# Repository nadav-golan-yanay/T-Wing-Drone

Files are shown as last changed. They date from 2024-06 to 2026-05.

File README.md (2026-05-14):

# T-Wing-Drone

**T-Wing** is a custom VTOL drone project I built as my final-year project in the Robotics program at Gvanim High School.  
The platform uses **three motors**, each mounted on a **servo-driven rotating mechanism**, combining multirotor control with custom mechanical design.

## Repository contents

This repository currently includes:

- `V22 full assembly 3D files/` — STL files for the full mechanical assembly
- `T-Wing_Params.params` — flight-controller parameter set
- `arducopter.apj` — ArduPilot firmware package used in this project

## Project highlights

- Custom airframe and wing/motor mounting system
- 3D-printed structural parts (PLA + ABS) with carbon-fiber reinforcements
- Iterative design based on real flight-test feedback
- Migration from early ESP32/Arduino prototypes to Pixhawk-based control

## Proof of success / flight tests

It took almost a year from the initial concept to the first successful takeoff.  
Flight tests are documented on my YouTube channel **NJGeek**:

- Channel: <https://www.youtube.com/channel/UCFTb9_tvUnTDQ8KEI29btOw>
- Playlist: <https://youtube.com/playlist?list=PLqjej9Hx4NUbdtqtBohuQlDSfjigC6vUl&si=ENThvdS27YvLaflj>

### First successful flight

My first successful flight was on **2023-05-19**:

- Video: <https://youtu.be/v9YFX8xqOcs>
- Clip asset:  
  <https://github.com/nadav-golan-yanay/T-Wing-Drone/assets/78790309/edb56a76-8f06-4417-a14c-41ca4fd376b4>

## Parts and 3D models

All model files are available in:

- [`V22 full assembly 3D files`](./V22%20full%20assembly%203D%20files)

Modeling and manufacturing workflow:

- CAD: [Onshape](https://www.onshape.com/en/)
- 3D printing: [FlashForge](https://flashforge.com/)

TWing-Full-V22

The assembly is built from four main modules: a body and three wings.  
Main material is PLA, with ABS used for heat-sensitive parts and carbon-fiber rods for reinforcement.

### Motor holder design notes

Exploded_Motor_Holder

The motor holder connects to a carbon-fiber bar using a clamp-based solution.  
During testing, motor heat caused PLA deformation, so the design evolved through several iterations:

1. ABS-only holder (rejected due to poor layer adhesion under load)
2. ABS spacers between motor and PLA base (improved, but not enough over time)
3. Additional thermal isolation layer between base and spacers (successful in long runs)

## Boards and controllers

The final version of the drone used a **Pixhawk 4 Mini** flight controller.

| Parameter | ESP32 | Arduino Uno | Pixhawk 4 Mini |
| :--- | :---: | :---: | :---: |
| Memory | 520 KB | 32 KB | 2 MB |
| Code stack | C++ | C++ | ArduPilot |
| Weight | 10 g | 25 g | 37.2 g |
| I/O voltage | 3.3 V | 5 V | 5 V |

### Why ESP32 and Arduino were used in early stages

The project started with ESP32 and Arduino due to budget limitations and available school hardware.  
That phase enabled rapid prototyping of:

- a custom radio system: <https://github.com/nadav-golan-yanay/com.git>
- motor/servo extension logic: <https://github.com/nadav-golan-yanay/Extender.git>
- custom PID experiments: <https://github.com/nadav-golan-yanay/PID.git>

This early work helped build system-level understanding before moving to Pixhawk + ArduPilot.

## Code and parameters

This repository includes the configuration artifacts used in the project:

- Parameters file: [`T-Wing_Params.params`](./T-Wing_Params.params)
- Firmware package: [`arducopter.apj`](./arducopter.apj)

> **Safety note:** Flight parameters and firmware should be reviewed and adapted for your frame, propulsion system, and local safety rules before use.

## Original Hebrew project book

This project was originally documented as a full project book in Hebrew for the school robotics program.  
It includes the design process, engineering decisions, manufacturing notes, and flight-test development timeline behind T-Wing.
You can read it here:

https://docs.google.com/document/d/e/2PACX-1vRpgUPn3u3C4NKBrrm5369ePE8NgqHe6AcITnAAplzpBRE5xgx34mOA12HqonQQBGQqTkdLsOp1IHl_/pub

## Acknowledgments

I’m deeply grateful to everyone who helped make this project possible:

In this project, I received help from many people, whom I would like to thank. First and foremost, I would like to thank my subject teachers, [Gal Arbel](https://github.com/galarb) and [Oded Valensi](). Whether in modeling, programming, manufacturing, or writing the report, Gal and Oded were always by my side and supported me. Thank you for helping to push me to the limits of my abilities and beyond; under your guidance, even the sky is not the limit.

I want to extend my gratitude to my parents who supported me throughout the entire project and encouraged me to pursue this field. Thank you for every model airplane and drone you bought me, each one helped me gain the knowledge that enabled me to build this project. Many thanks to [Efi Kastiel](https://www.linkedin.com/search/results/all/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) from [Efix-Aviation](https://www.linkedin.com/company/efixaviation/?originalSubdomain=il), who donated equipment and provided training regarding the drone. A big thank you to [Ariel Dubrovinski](), who guided me on how to use the Pixhawk controller and how to work with PID systems.

Thank you to the students from grades 9 and 7: [Tomer Ozer](https://github.com/TomerOzer), [Noam Ron](https://github.com/NoamRon1), [Yehav Kosi Friedman](https://github.com/yahavkosoi), [Dan Katzenellenbogen](https://github.com/Dan-Katzenellenbogen), [Yoav Aharoni](), [Neta Shen-Or](), [Hadas Rahman](), and [Yoav Paz](https://github.com/YoavPaz). Thank you for your help in building the project and supporting the code, whether it was just holding a part while I drilled or reviewing the code. You all helped greatly, and for that, I thank you.

A special thank you to [Roee Glotman](https://github.com/Roee-dev), my classmate, who was my partner at the beginning of the project. Many thanks to my fellow students in the subject: [Yotam Sharon](), [Daniel Shor](), [Dror Chen](), [Ori Zalgman](), [Daniel Semelik](https://github.com/DanielSmelik), [Yuval Rahman](), [Eran Salomon]() and [Raviv Klein](https://github.com/raviviviviv). Thank you very much for the help and support, for being with me during flight tests, for helping me film, and for letting me print before you so I could progress. Thank you very much to the school for the lab and project funding.

Finally, a huge thank you to my (ex)girlfriend, Daria Hebron. Thank you for your support and understanding. Thank you for every glass of water or toast you brought me in the late hours of the night when I was sitting at the computer working, thank you for letting me use your car to transport equipment, and thank you for all the emotional support you provided during all the difficulties.

Thank you all for helping turn this idea into a flying system.

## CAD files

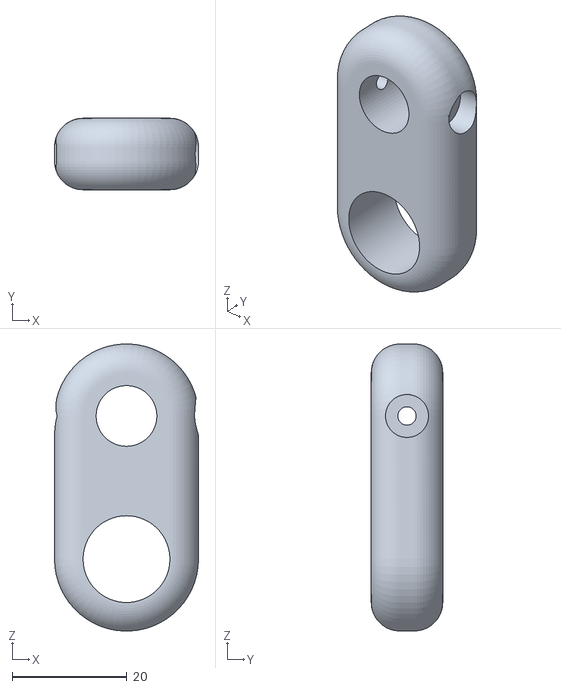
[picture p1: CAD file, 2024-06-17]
V22 full assembly 3D files/Biring Holder.stl
25.1 x 12.5 x 50.1

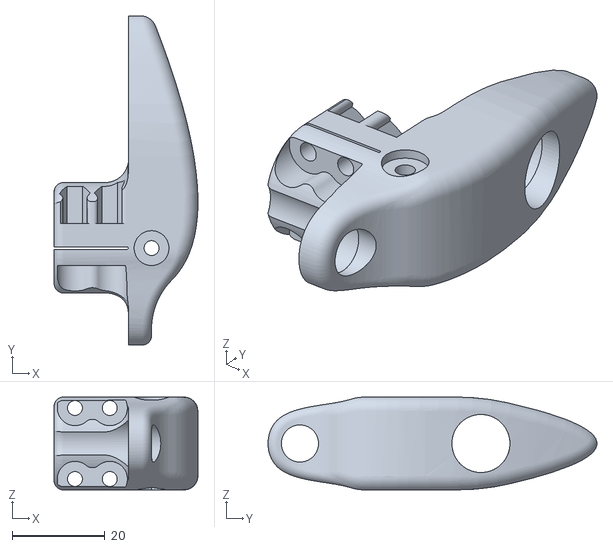
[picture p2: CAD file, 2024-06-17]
V22 full assembly 3D files/Carbon Fiber bar end.stl
31.0 x 70.9 x 20.0

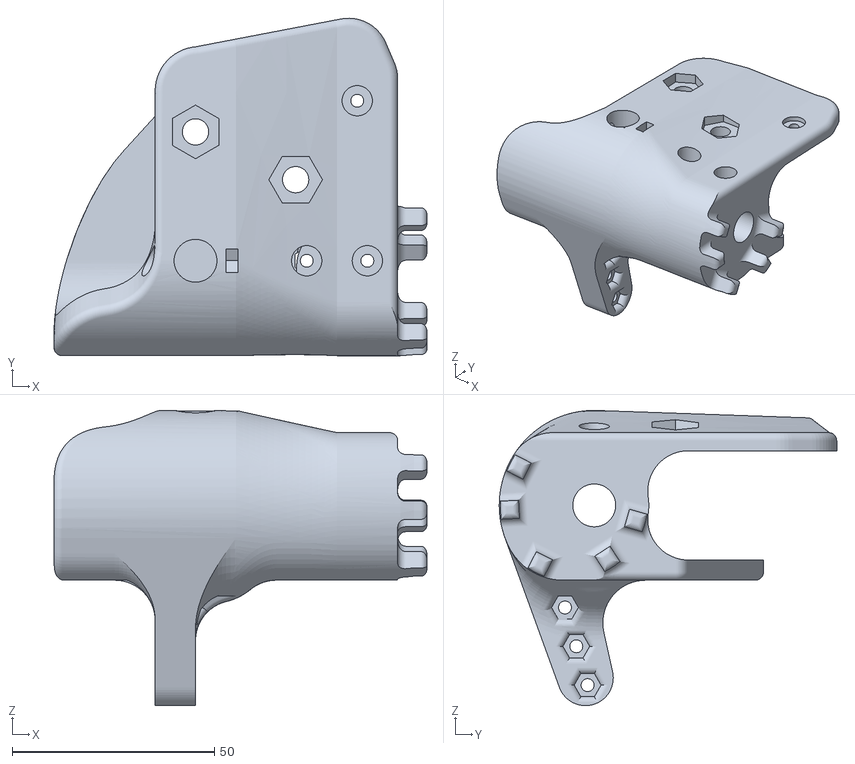
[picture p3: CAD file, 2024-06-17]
V22 full assembly 3D files/Wings Holder Left.stl
92.2 x 83.5 x 73.0

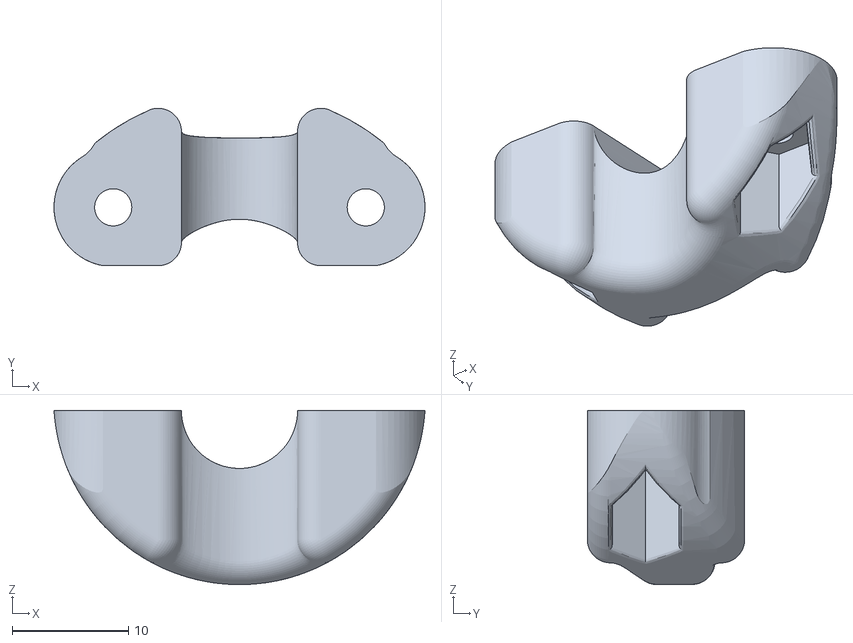
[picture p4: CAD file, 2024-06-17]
V22 full assembly 3D files/Motor holder to carbon fiber bar connector.stl
32.0 x 13.6 x 15.0

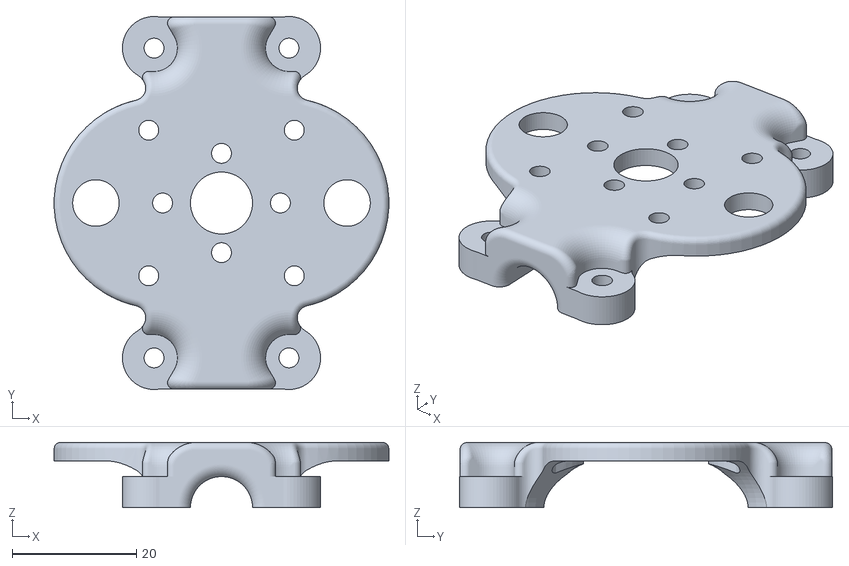
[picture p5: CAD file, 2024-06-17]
V22 full assembly 3D files/Motor Holder Base.stl
54.0 x 60.1 x 10.5

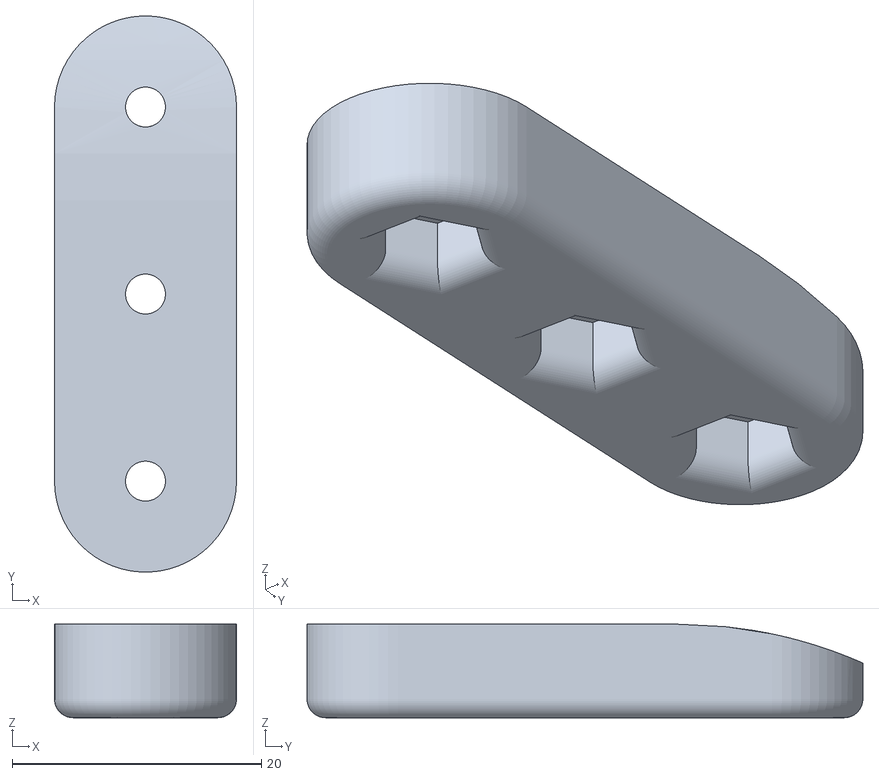
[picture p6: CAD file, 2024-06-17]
V22 full assembly 3D files/body to back wing connector.stl
14.6 x 44.6 x 7.50

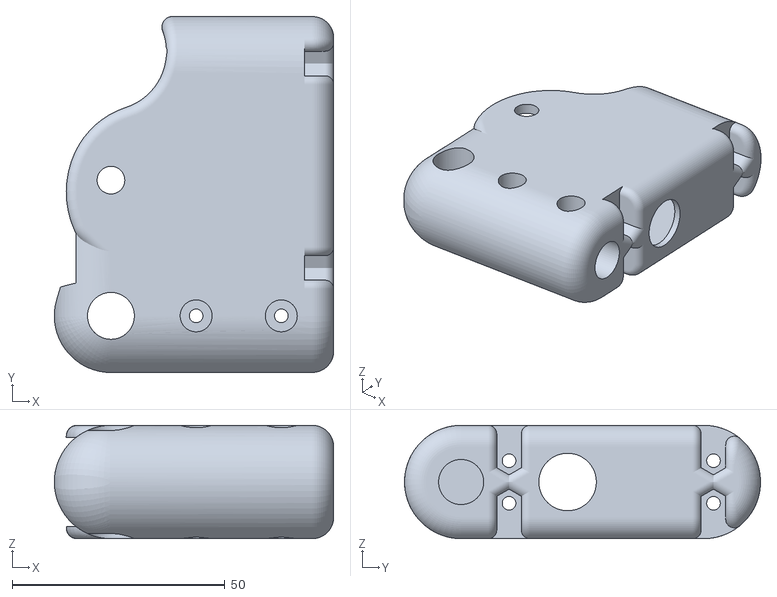
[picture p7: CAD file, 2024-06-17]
V22 full assembly 3D files/ Servo Holder.stl
65.6 x 83.6 x 26.6

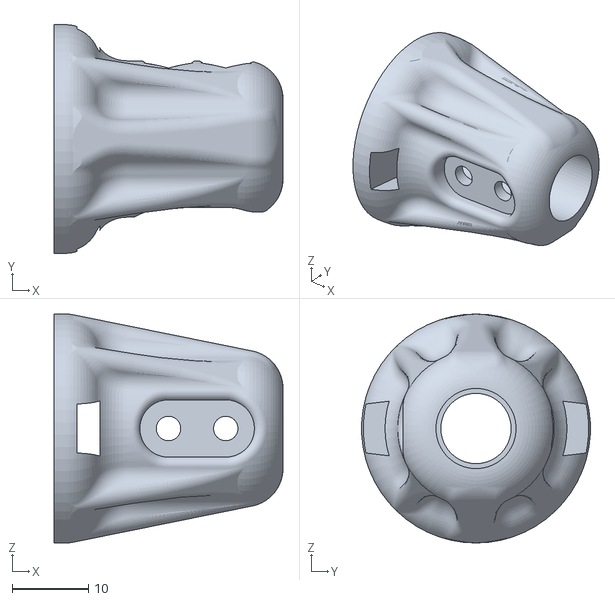
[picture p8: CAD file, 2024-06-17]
V22 full assembly 3D files/Stormtrooper helmet.stl
30.0 x 30.0 x 30.0

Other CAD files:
V22 full assembly 3D files/Body.stl
V22 full assembly 3D files/Wings Holder Right.stl

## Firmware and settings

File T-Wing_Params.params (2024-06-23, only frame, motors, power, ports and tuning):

1	1	ATC_ANGLE_BOOST	1	2
1	1	ATC_ANG_LIM_TC	1.000000000000000000	9
1	1	ATC_ANG_PIT_P	4.500000000000000000	9
1	1	ATC_ANG_RLL_P	4.500000000000000000	9
1	1	ATC_ANG_YAW_P	4.500000000000000000	9
1	1	ATC_RATE_FF_ENAB	1	2
1	1	ATC_RATE_P_MAX	0.000000000000000000	9
1	1	ATC_RATE_R_MAX	0.000000000000000000	9
1	1	ATC_RATE_Y_MAX	0.000000000000000000	9
1	1	ATC_RAT_PIT_D	0.003599999938160181	9
1	1	ATC_RAT_PIT_FF	0.000000000000000000	9
1	1	ATC_RAT_PIT_FLTD	20.000000000000000000	9
1	1	ATC_RAT_PIT_FLTE	0.000000000000000000	9
1	1	ATC_RAT_PIT_FLTT	20.000000000000000000	9
1	1	ATC_RAT_PIT_I	0.135000005364418030	9
1	1	ATC_RAT_PIT_IMAX	0.500000000000000000	9
1	1	ATC_RAT_PIT_P	0.135000005364418030	9
1	1	ATC_RAT_PIT_SMAX	0.000000000000000000	9
1	1	ATC_RAT_RLL_D	0.003599999938160181	9
1	1	ATC_RAT_RLL_FF	0.000000000000000000	9
1	1	ATC_RAT_RLL_FLTD	20.000000000000000000	9
1	1	ATC_RAT_RLL_FLTE	0.000000000000000000	9
1	1	ATC_RAT_RLL_FLTT	20.000000000000000000	9
1	1	ATC_RAT_RLL_I	0.135000005364418030	9
1	1	ATC_RAT_RLL_IMAX	0.500000000000000000	9
1	1	ATC_RAT_RLL_P	0.135000005364418030	9
1	1	ATC_RAT_RLL_SMAX	0.000000000000000000	9
1	1	ATC_RAT_YAW_D	0.000000000000000000	9
1	1	ATC_RAT_YAW_FF	0.000000000000000000	9
1	1	ATC_RAT_YAW_FLTD	100.000000000000000000	9
1	1	ATC_RAT_YAW_FLTE	2.500000000000000000	9
1	1	ATC_RAT_YAW_FLTT	20.000000000000000000	9
1	1	ATC_RAT_YAW_I	0.017999999225139618	9
1	1	ATC_RAT_YAW_IMAX	0.500000000000000000	9
1	1	ATC_RAT_YAW_P	0.180000007152557373	9
1	1	ATC_RAT_YAW_SMAX	0.000000000000000000	9
1	1	BATT2_MONITOR	0	2
1	1	BATT3_MONITOR	0	2
1	1	BATT4_MONITOR	0	2
1	1	BATT5_MONITOR	0	2
1	1	BATT6_MONITOR	0	2
1	1	BATT7_MONITOR	0	2
1	1	BATT8_MONITOR	0	2
1	1	BATT9_MONITOR	0	2
1	1	BATT_AMP_OFFSET	0.000000000000000000	9
1	1	BATT_AMP_PERVLT	36.363998413085937500	9
1	1	BATT_ARM_MAH	0	6
1	1	BATT_ARM_VOLT	0.000000000000000000	9
1	1	BATT_CAPACITY	1300	6
1	1	BATT_CRT_MAH	0.000000000000000000	9
1	1	BATT_CRT_VOLT	0.000000000000000000	9
1	1	BATT_CURR_PIN	1	2
1	1	BATT_FS_CRT_ACT	0	2
1	1	BATT_FS_LOW_ACT	0	2
1	1	BATT_FS_VOLTSRC	0	2
1	1	BATT_LOW_MAH	0.000000000000000000	9
1	1	BATT_LOW_TIMER	10	2
1	1	BATT_LOW_VOLT	10.500000000000000000	9
1	1	BATT_MONITOR	4	2
1	1	BATT_OPTIONS	0	6
1	1	BATT_SERIAL_NUM	-1	6
1	1	BATT_VLT_OFFSET	0.000000000000000000	9
1	1	BATT_VOLT_MULT	18.181999206542968750	9
1	1	BATT_VOLT_PIN	0	2
1	1	FLTMODE1	0	2
1	1	FLTMODE2	0	2
1	1	FLTMODE3	9	2
1	1	FLTMODE4	9	2
1	1	FLTMODE5	2	2
1	1	FLTMODE6	2	2
1	1	FLTMODE_CH	0	2
1	1	FRAME_CLASS	7	2
1	1	FRAME_TYPE	1	2
1	1	INS_GYRO_FILTER	20	4
1	1	INS_HNTCH_ENABLE	0	2
1	1	MOT_BAT_CURR_MAX	0.000000000000000000	9
1	1	MOT_BAT_CURR_TC	5.000000000000000000	9
1	1	MOT_BAT_IDX	0	2
1	1	MOT_BAT_VOLT_MAX	0.000000000000000000	9
1	1	MOT_BAT_VOLT_MIN	0.000000000000000000	9
1	1	MOT_BOOST_SCALE	0.000000000000000000	9
1	1	MOT_HOVER_LEARN	2	2
1	1	MOT_PWM_MAX	2000	4
1	1	MOT_PWM_MIN	1000	4
1	1	MOT_PWM_TYPE	0	2
1	1	MOT_SAFE_DISARM	0	2
1	1	MOT_SAFE_TIME	1.000000000000000000	9
1	1	MOT_SLEW_DN_TIME	0.000000000000000000	9
1	1	MOT_SLEW_UP_TIME	0.000000000000000000	9
1	1	MOT_SPIN_ARM	0.100000001490116119	9
1	1	MOT_SPIN_MAX	0.949999988079071045	9
1	1	MOT_SPIN_MIN	0.150000005960464478	9
1	1	MOT_SPOOL_TIME	0.500000000000000000	9
1	1	MOT_THST_EXPO	0.649999976158142090	9
1	1	MOT_THST_HOVER	0.349999994039535522	9
1	1	MOT_YAW_HEADROOM	200	4
1	1	MOT_YAW_SV_ANGLE	30.000000000000000000	9
1	1	SERIAL0_BAUD	115	6
1	1	SERIAL0_PROTOCOL	2	2
1	1	SERIAL1_BAUD	57	6
1	1	SERIAL1_OPTIONS	0	4
1	1	SERIAL1_PROTOCOL	2	2
1	1	SERIAL2_BAUD	57	6
1	1	SERIAL2_OPTIONS	0	4
1	1	SERIAL2_PROTOCOL	2	2
1	1	SERIAL3_BAUD	38	6
1	1	SERIAL3_OPTIONS	0	4
1	1	SERIAL3_PROTOCOL	5	2
1	1	SERIAL4_BAUD	38	6
1	1	SERIAL4_OPTIONS	8	4
1	1	SERIAL4_PROTOCOL	23	2
1	1	SERIAL5_BAUD	57	6
1	1	SERIAL5_OPTIONS	0	4
1	1	SERIAL5_PROTOCOL	-1	2
1	1	SERIAL6_BAUD	115200	6
1	1	SERIAL6_OPTIONS	0	4
1	1	SERIAL6_PROTOCOL	2	2
1	1	SERVO1_FUNCTION	33	4
1	1	SERVO1_MAX	2000	4
1	1	SERVO1_MIN	1000	4
1	1	SERVO1_REVERSED	0	2
1	1	SERVO1_TRIM	1500	4
1	1	SERVO2_FUNCTION	34	4
1	1	SERVO2_MAX	2000	4
1	1	SERVO2_MIN	1000	4
1	1	SERVO2_REVERSED	0	2
1	1	SERVO2_TRIM	1500	4
1	1	SERVO3_FUNCTION	0	4
1	1	SERVO3_MAX	1900	4
1	1	SERVO3_MIN	1100	4
1	1	SERVO3_REVERSED	0	2
1	1	SERVO3_TRIM	1500	4
1	1	SERVO4_FUNCTION	36	4
1	1	SERVO4_MAX	2000	4
1	1	SERVO4_MIN	1000	4
1	1	SERVO4_REVERSED	0	2
1	1	SERVO4_TRIM	1500	4
1	1	SERVO5_FUNCTION	55	4
1	1	SERVO5_MAX	1900	4
1	1	SERVO5_MIN	1100	4
1	1	SERVO5_REVERSED	1	2
1	1	SERVO5_TRIM	1500	4
1	1	SERVO6_FUNCTION	55	4
1	1	SERVO6_MAX	1900	4
1	1	SERVO6_MIN	1100	4
1	1	SERVO6_REVERSED	1	2
1	1	SERVO6_TRIM	1500	4
1	1	SERVO7_FUNCTION	39	4
1	1	SERVO7_MAX	1900	4
1	1	SERVO7_MIN	1100	4
1	1	SERVO7_REVERSED	0	2
1	1	SERVO7_TRIM	1500	4
1	1	SERVO8_FUNCTION	56	4
1	1	SERVO8_MAX	1900	4
1	1	SERVO8_MIN	1100	4
1	1	SERVO8_REVERSED	0	2
1	1	SERVO8_TRIM	1500	4
1	1	SERVO9_FUNCTION	0	4
1	1	SERVO9_MAX	1900	4
1	1	SERVO9_MIN	1100	4
1	1	SERVO9_REVERSED	0	2
1	1	SERVO9_TRIM	1500	4

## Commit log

2024-06-17 adding 3D files
    [V22 full assembly - Back Wing Base.stl, V22 full assembly - Biring Holder.stl, V22 full assembly - Body.stl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]
2024-06-17 Rename V22 full assembly - Back Wing Base.stl to V22 full assembly 3D files/Back Wing Base.stl
    [Back Wing Base.stl, V22 full assembly - Back Wing Base.stl]
2024-06-17 Rename V22 full assembly - Biring Holder.stl to V22 full assembly 3D files/Biring Holder.stl
    [Biring Holder.stl]
2024-06-17 Rename V22 full assembly - Body.stl to V22 full assembly 3D files/Body.stl
    [Body.stl, V22 full assembly - Body.stl]
2024-06-17 Rename V22 full assembly - Carbon Fiber bar end.stl to V22 full assembly 3D files/Carbon Fiber bar end.stl
    [Carbon Fiber bar end.stl]
2024-06-17 Rename V22 full assembly - Motor Holder Base.stl to V22 full assembly 3D files/Motor Holder Base.stl
    [Motor Holder Base.stl]
2024-06-17 Rename V22 full assembly - Motor holder to carbon fiber bar connector.stl to V22 full assembly 3D files/Motor holder to carbon fiber bar connector.stl
    [Motor holder to carbon fiber bar connector.stl]
2024-06-17 Rename V22 full assembly - Servo Holder.stl to V22 full assembly 3D files/ Servo Holder.stl
    [Servo Holder.stl]
2024-06-17 Rename V22 full assembly - Stormtrooper helmet.stl to V22 full assembly 3D files/Stormtrooper helmet.stl
    [Stormtrooper helmet.stl]
2024-06-17 Rename V22 full assembly - Wings Holder Left.stl to V22 full assembly 3D files/Wings Holder Left.stl
    [Wings Holder Left.stl]
2024-06-17 Rename V22 full assembly - Wings Holder Right.stl to V22 full assembly 3D files/Wings Holder Right.stl
    [Wings Holder Right.stl]
2024-06-17 Rename V22 full assembly - body to back wing connector.stl to V22 full assembly 3D files/body to back wing connector.stl
    [body to back wing connector.stl]
2024-06-21 Update README.md
    motor holder
2024-10-23 arducopter T-wing firmwire
2026-05-14 docs: finish and rewrite README
    Agent-Logs-Url: https://github.com/nadav-golan-yanay/T-Wing-Drone/sessions/16695735-46d3-400c-82f9-82462b8db6f9
2026-05-14 Add README note about original Hebrew project book
    Agent-Logs-Url: https://github.com/nadav-golan-yanay/T-Wing-Drone/sessions/0608a3f9-8296-413a-a28b-83018009f8f4
